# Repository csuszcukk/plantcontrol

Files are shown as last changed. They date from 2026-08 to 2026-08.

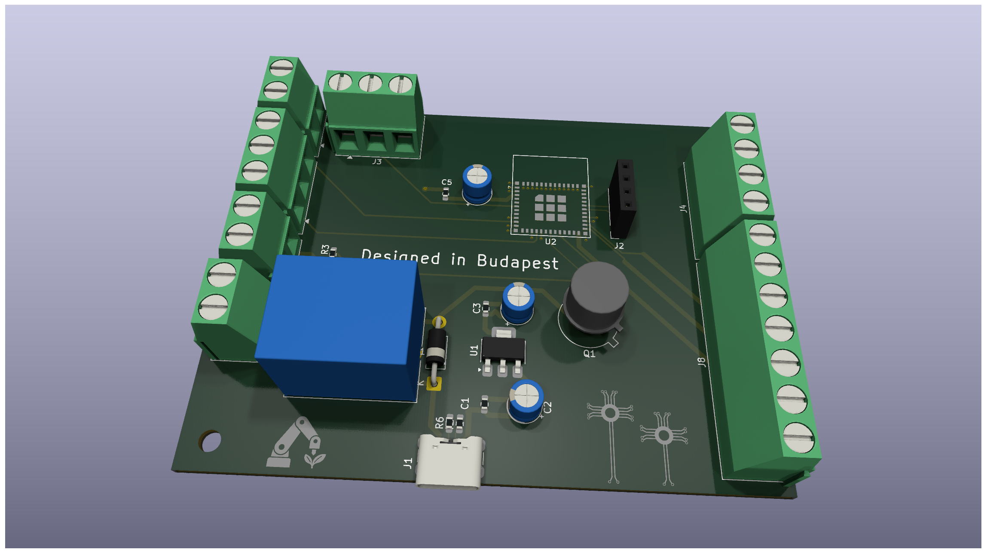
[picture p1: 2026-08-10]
pcb/mainboard/res/pcb.png

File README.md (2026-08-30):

# PlantControl
make a smart pot for plants



## Features

* Automatic watering and light control
* Humidity and temperature monitoring
* Soil temperature and moisture monitoring
* Low water level alert
* Custom water container design
* Compatible with all plants and pots

## How to Build It

1. **PCB Fabrication:** Order the PCBs from any manufacturer (ordering a stencil is recommended).
2. **Heat Dissipation (Optional):** If you plan to use LEDs, mount them on an aluminum sheet using thermal conductive tape for proper heat dissipation.
3. **Components:** Order the necessary components listed in the Bill of Materials (BOM) — feel free to modify or skip non-essential parts.
4. **3D Printing:** Print the structural parts (PLA is recommended for the main board enclosure, and PETG for the water container).
5. **Assembly:** Solder all components onto the PCB.
6. **Preparation:** Connect the boot configuration pins and plug in the power source.
7. **Flashing Interface:** Connect your USB-to-UART bridge (make sure RX and TX lines are swapped).
8. **Firmware Installation (MicroPython):** Flash the ESP32 with the MicroPython firmware (see the official [MicroPython ESP32 Documentation](https://docs.micropython.org/en/latest/esp32/tutorial/intro.html)).
9. **Uploading Code:** Flash `main.py` onto the board (follow this [MicroPython Flashing Guide](https://georgefreedom.com/ignition-sequence-how-to-flash-micropython-onto-your-esp32/)).
10. **Cleanup:** Remove the boot mode jumpers and the UART adapter, then disconnect power.
11. **Wiring:** Connect all peripherals and modules to their respective header pins (labels are silkscreened on the PCB for guidance).
12. **Final Mounting:** Secure the sensors and the main board inside the enclosure (double-sided mounting tape works great).
13. **Power On:** Reconnect power to the board.
14. **Done!** Your plant controller is ready to go.

> **Pro Tip:** On first boot (or if it cannot connect to a saved network), the device will host a Wi-Fi Access Point. Connect to it to enter your local Wi-Fi SSID and password via the captive portal. Don't forget to enter your ThingSpeak API key in the configuration file to enable telemetry logging!

## How It Works

PlantControl is an automated, ESP32-C6-powered plant monitoring and maintenance system running on custom MicroPython firmware. It continuously monitors environmental conditions and manages irrigation and lighting using asynchronous event loops.

### Core Architecture

* **Sensor Data Acquisition:** The system periodically samples soil moisture, ambient light, and air temperature/humidity levels. 
* **Automated Logic & Safety:** If soil moisture drops below the predefined threshold, the MCU triggers a relay/MOSFET to activate the water pump. It includes safety timers to prevent over-watering or running the pump dry.
* **Local UI & Status:** A circular GC9A01 SPI display provides real-time readout of plant metrics and device status directly on the enclosure.
* **Power & Load Management:** High-side MOSFET switching ensures power is delivered efficiently to peripherals (pumps, LEDs) only when needed, minimizing idle power consumption.
* **Connectivity & Telemetry:** Integrated Wi-Fi connects to local infrastructure to stream telemetry to ThingSpeak. If network connection fails, it automatically spins up a Wi-Fi Access Point with a captive portal for re-configuration.

## Component Sourcing & Logistics

To optimize the project budget and lead times, a hybrid sourcing strategy is used:

- **LCSC:** Used for standard SMD components, passives, ICs, and microcontrollers to take advantage of low bulk pricing.
- **HESTORE (EU Local Distributor):** Used for specific sensors, modules, and components unavailable on LCSC or needed quickly.

All BOM prices from HESTORE have been converted from HUF to USD using current market exchange rates.

## License

This project is licensed under the MIT License - see the [LICENSE](LICENSE) file for details.

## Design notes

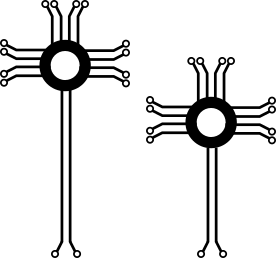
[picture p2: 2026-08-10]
pcb/mainboard/res/path1317-7.png

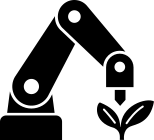
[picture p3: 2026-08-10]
pcb/mainboard/res/g1170.png

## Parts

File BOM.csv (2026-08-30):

Reference | Qty | Value | DNP | Exclude from BOM | Exclude from Board | Exclude from Simulation | Exclude from Position Files | Footprint | Datasheet | jlc part # | amazon link
J10 | 1 | Screw_Terminal_01x04 |  |  |  |  | ${EXCLUDE_FROM_POS_FILES} | TerminalBlock_Phoenix:TerminalBlock_Phoenix_MKDS-1,5-4_1x04_P5.00mm_Horizontal |  | C90087
R1 | 1 | 5,1k |  |  |  |  | ${EXCLUDE_FROM_POS_FILES} | Resistor_SMD:R_0603_1608Metric_Pad0.98x0.95mm_HandSolder |  | C177348
R4 | 1 | VT93xx |  |  |  |  | ${EXCLUDE_FROM_POS_FILES} | OptoDevice:R_LDR_4.9x4.2mm_P2.54mm_Vertical | http://www.produktinfo.conrad.com/datenblaetter/125000-149999/140375-da-01-en-FOTOWIDERSTAND__VT_93_N2__THT_.pdf | C10077
R5 | 1 | 10k |  |  |  |  | ${EXCLUDE_FROM_POS_FILES} | Resistor_SMD:R_0603_1608Metric_Pad0.98x0.95mm_HandSolder |  | C2906982
U3 | 1 | AM2302 |  |  |  |  | ${EXCLUDE_FROM_POS_FILES} | Sensor:ASAIR_AM2302_P2.54mm_Lead2.75mm_TabDown | http://akizukidenshi.com/download/ds/aosong/AM2302.pdf | C83988
USB1 | 1 | TYPE-C 6P |  |  |  |  |  | lcsc_import:TYPE-C-SMD_TYPE-C-6P-073 | https://lcsc.com/product-detail/USB-Connectors_SHOU-HAN-TYPE-C-6P-073_C668623.html | C668623
U2 | 1 | AMS1117-3.3 |  |  |  |  |  | Package_TO_SOT_SMD:SOT-223-3_TabPin2 | http://www.advanced-monolithic.com/pdf/ds1117.pdf | C6186
U1 | 1 | ESP32-C6-MINI-1 |  |  |  |  |  | Library:ESP32-C6-MINI-1psa | https://www.espressif.com/sites/default/files/documentation/esp32-c6-mini-1_mini-1u_datasheet_en.pdf | C5736265
R8,R9 | 2 | 5,1k |  |  |  |  |  | Resistor_SMD:R_0603_1608Metric_Pad0.98x0.95mm_HandSolder |  | C177348
R3 | 1 | 1k |  |  |  |  |  | Resistor_SMD:R_0603_1608Metric_Pad0.98x0.95mm_HandSolder |  | C2907002
R2,R4,R6,R7 | 4 | 10k |  |  |  |  |  | Resistor_SMD:R_0603_1608Metric_Pad0.98x0.95mm_HandSolder |  | C2906982
R1 | 1 | 470 |  |  |  |  |  | Resistor_SMD:R_0603_1608Metric_Pad0.98x0.95mm_HandSolder |  | C23179
Q2 | 1 | 2N2222A |  |  |  |  |  | Package_TO_SOT_THT:TO-39-3 | https://www.onsemi.com/pub/Collateral/2N3903-D.PDF | C118536
Q1 | 1 | AO3400A |  |  |  |  |  | Package_TO_SOT_SMD:SOT-23 | http://www.aosmd.com/pdfs/datasheet/AO3400A.pdf | C20917
K1 | 1 | SANYOU_SRD_Form_A |  |  |  |  |  | Relay_THT:Relay_SPDT_SANYOU_SRD_Series_Form_C | http://www.sanyourelay.ca/public/products/pdf/SRD.pdf | C35449
J11 | 1 | Conn_01x02_Pin |  |  |  |  |  | Connector_PinHeader_2.54mm:PinHeader_1x02_P2.54mm_Vertical |  | C37208
J8 | 1 | Conn_01x04_Pin |  |  |  |  |  | Connector_PinSocket_2.54mm:PinSocket_1x04_P2.54mm_Vertical |  | C37208
J6 | 1 | Screw_Terminal_01x07 |  |  |  |  |  | TerminalBlock_Phoenix:TerminalBlock_Phoenix_MKDS-1,5-7_1x07_P5.00mm_Horizontal |  | C395855
J4,J5 | 2 | Screw_Terminal_01x03 |  |  |  |  |  | TerminalBlock_Phoenix:TerminalBlock_Phoenix_MKDS-1,5-3_1x03_P5.00mm_Horizontal |  | C8270
J3,J7,J9 | 3 | Screw_Terminal_01x02 |  |  |  |  |  | TerminalBlock_Phoenix:TerminalBlock_Phoenix_MKDS-1,5-2_1x02_P5.00mm_Horizontal |  | C3703
J2 | 1 | Screw_Terminal_01x04 |  |  |  |  |  | TerminalBlock_Phoenix:TerminalBlock_Phoenix_MKDS-1,5-4_1x04_P5.00mm_Horizontal |  | C90087
D1 | 1 | 1N4001 |  |  |  |  |  | Diode_THT:D_DO-41_SOD81_P10.16mm_Horizontal | http://www.vishay.com/docs/88503/1n4001.pdf | C2456
C2,C4,C6 | 3 | 100nF |  |  |  |  |  | Resistor_SMD:R_0603_1608Metric_Pad0.98x0.95mm_HandSolder |  | C1591
C1,C3,C5 | 3 | 10uF |  |  |  |  |  | Capacitor_THT:CP_Radial_D5.0mm_P2.00mm |  | C216288
~ | 1 |  |  |  |  |  |  | small circle spi sreen | ~ | ~ | https://www.amazon.com/Screen-Display-240x240-Interface-Arduino/dp/B0GR44PSBL/132-4224079-3597343
~ | 1 |  |  |  |  |  |  | water sensor | ~ | ~ | https://www.amazon.com/Ximimark-Sensor-Horizontal-Switch-Arduino/dp/B0B7WPBPBC
~ | 1 |  |  |  |  |  |  | power suply for the led | ~ | ~ | https://www.amazon.com/dp/B0781JC2WK?_encoding=UTF8&psc=1
~ | 1 |  |  |  |  |  |  | usb module | ~ | ~ | https://www.amazon.com/DSD-TECH-SH-U09C2-Debugging-Programming/dp/B07TXVRQ7V
~ | 1 |  |  |  |  |  |  | soil moistor sensor | ~ | ~ | https://www.amazon.com/VKLSVAN-Capacitive-Corrosion-Resistant-Detection/dp/B0DQSCD5CV
~ | 1 | 5V |  |  |  |  |  | pump | ~ | ~ | https://www.amazon.com/dp/B09GW5X4P2?_encoding=UTF8&psc=1
~ | 2m |  |  |  |  |  |  | pipes for the pump | ~ | ~ | https://www.amazon.com/Silicone-Flexible-Rubber-Tubing-Transparent/dp/B08HJJ13FG?
~ | 1 |  |  |  |  |  |  | Red Led | ~ | ~ | https://www.amazon.com/Cleiscry-Power-3W-Emitter-Components/dp/B0BKSL2HCC
~ | 1 |  |  |  |  |  |  | Blue Led | ~ | ~ | https://www.amazon.com/Cleiscry-Power-3W-Emitter-Components/dp/B0BKSMD3P9/ref=sr_1_4
 | 1 |  |  |  |  |  |  | power suply for the pump | ~ | ~ | same as the led but an another modul
 | 1 |  |  |  |  |  |  | termal tape |  | ~ | https://www.amazon.com/Thermal-Adhesive-Performance-Heatsink-Computer/dp/B085CLXM7J/ref=sr_1_3
 | 1 |  |  |  |  |  |  | plant pot |  | ~ | https://www.amazon.com/Dvine-Dev-Decorative-Gardening-Succulents/dp/B0D1G1N9BP/ref=sr_1_13

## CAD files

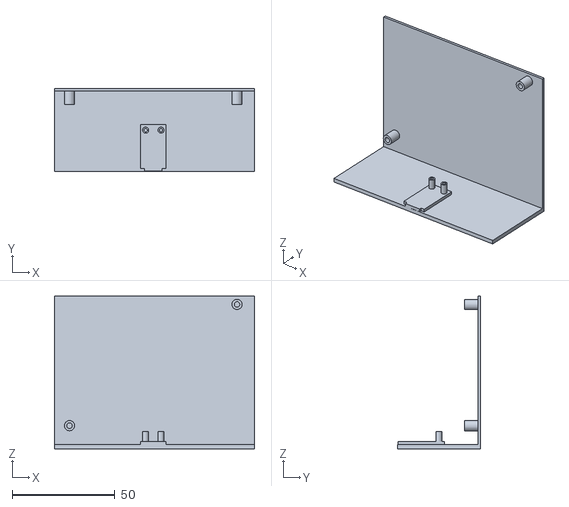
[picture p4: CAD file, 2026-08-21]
cad models/main board carrier.stl
97.3 x 40.2 x 74.2

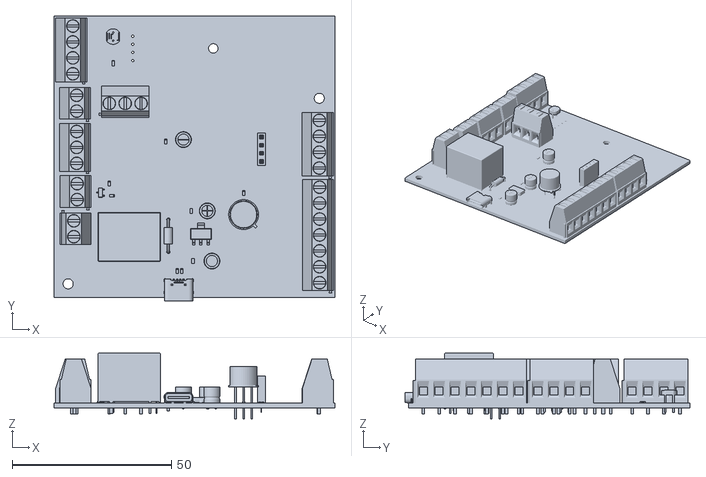
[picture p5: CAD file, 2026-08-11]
cad models/stl/main board.stl
88.3 x 89.4 x 20.6

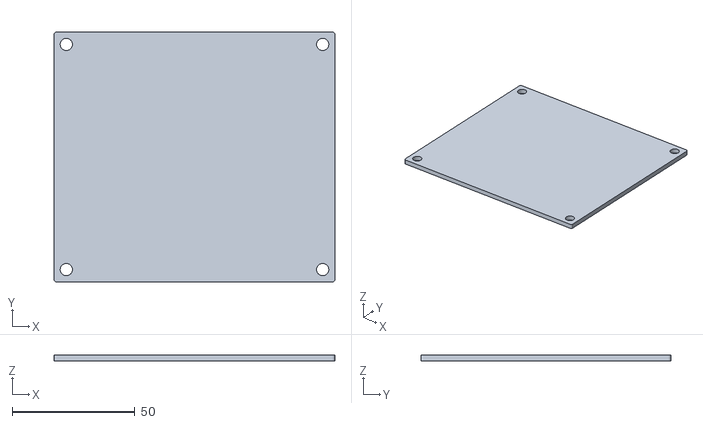
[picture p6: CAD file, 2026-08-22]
cad models/stl/led board.stl
114.3 x 101.6 x 2.50

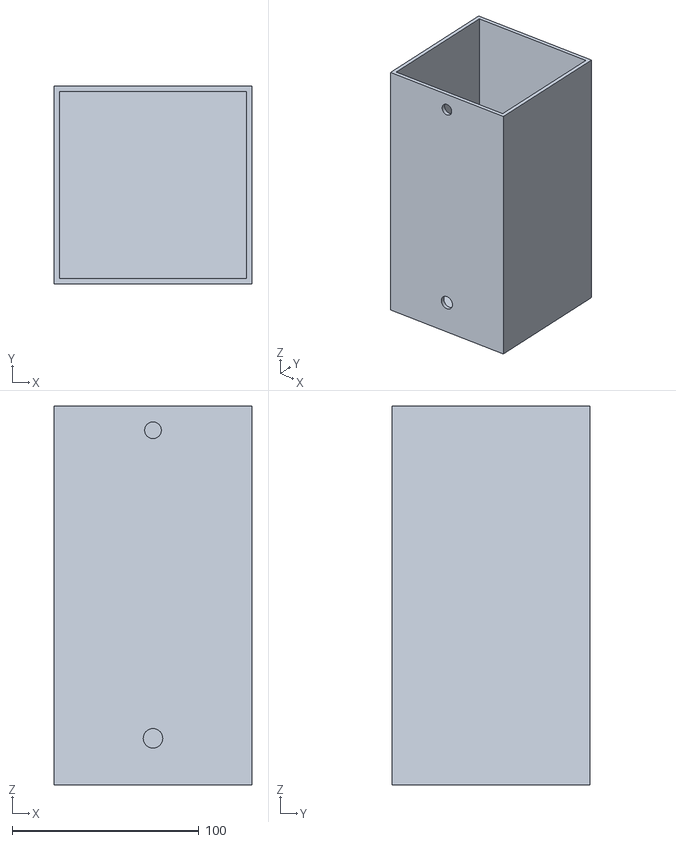
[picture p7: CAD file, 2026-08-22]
cad models/stl/watercontainer.stl
106.0 x 106.0 x 203.0

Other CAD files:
pcb/mainboard/pcb.step
cad models/stl/main board carrier.stl

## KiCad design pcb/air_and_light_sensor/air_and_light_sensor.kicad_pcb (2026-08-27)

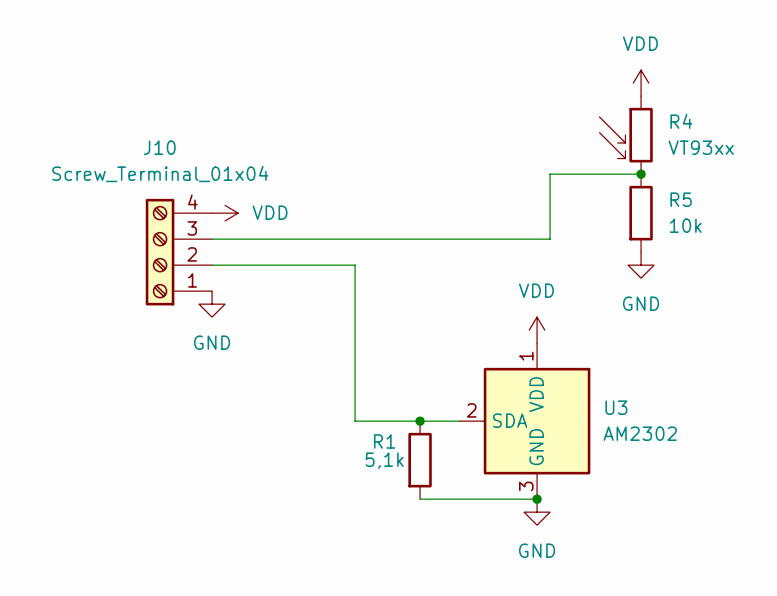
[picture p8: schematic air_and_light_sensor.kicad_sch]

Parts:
J10: Screw_Terminal_01x04; TerminalBlock_Phoenix_MKDS-1,5-4_1x04_P5.00mm_Horizontal; jlc part # C90087
R1: 5,1k; R_0603_1608Metric_Pad0.98x0.95mm_HandSolder; jlc part # C177348
R4: VT93xx; R_LDR_4.9x4.2mm_P2.54mm_Vertical; jlc part # C10077
R5: 10k; R_0603_1608Metric_Pad0.98x0.95mm_HandSolder; jlc part # C2906982
U3: AM2302; ASAIR_AM2302_P2.54mm_Lead2.75mm_TabDown; jlc part # C83988

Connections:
GND: J10.1, R1.2, R5.2, U3.3 (GND), U3.4 (GND)
unnamed: J10.2, R1.1, U3.2 (SDA)
unnamed: J10.3, R4.2, R5.1
VDD: J10.4, R4.1, U3.1 (VDD)

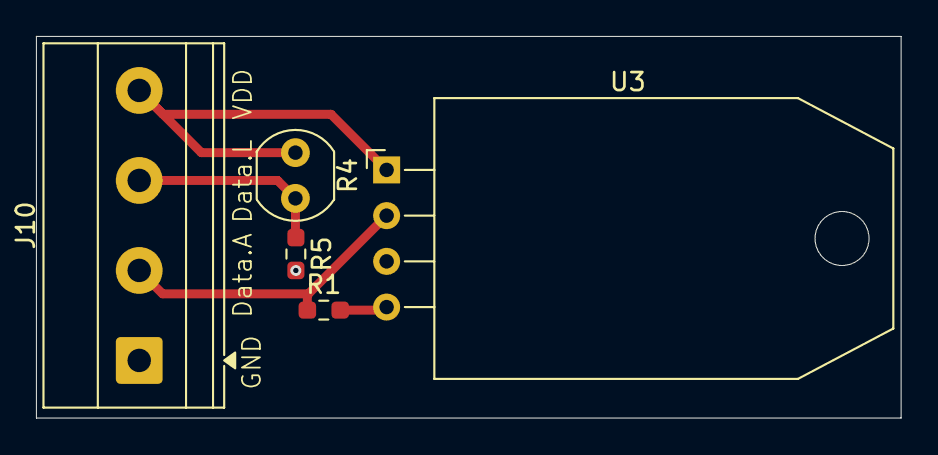
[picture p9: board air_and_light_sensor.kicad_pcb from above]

Board: 2 copper layers, 48.0 x 21.2 mm, 5 parts (0 on the bottom side), 4 nets.

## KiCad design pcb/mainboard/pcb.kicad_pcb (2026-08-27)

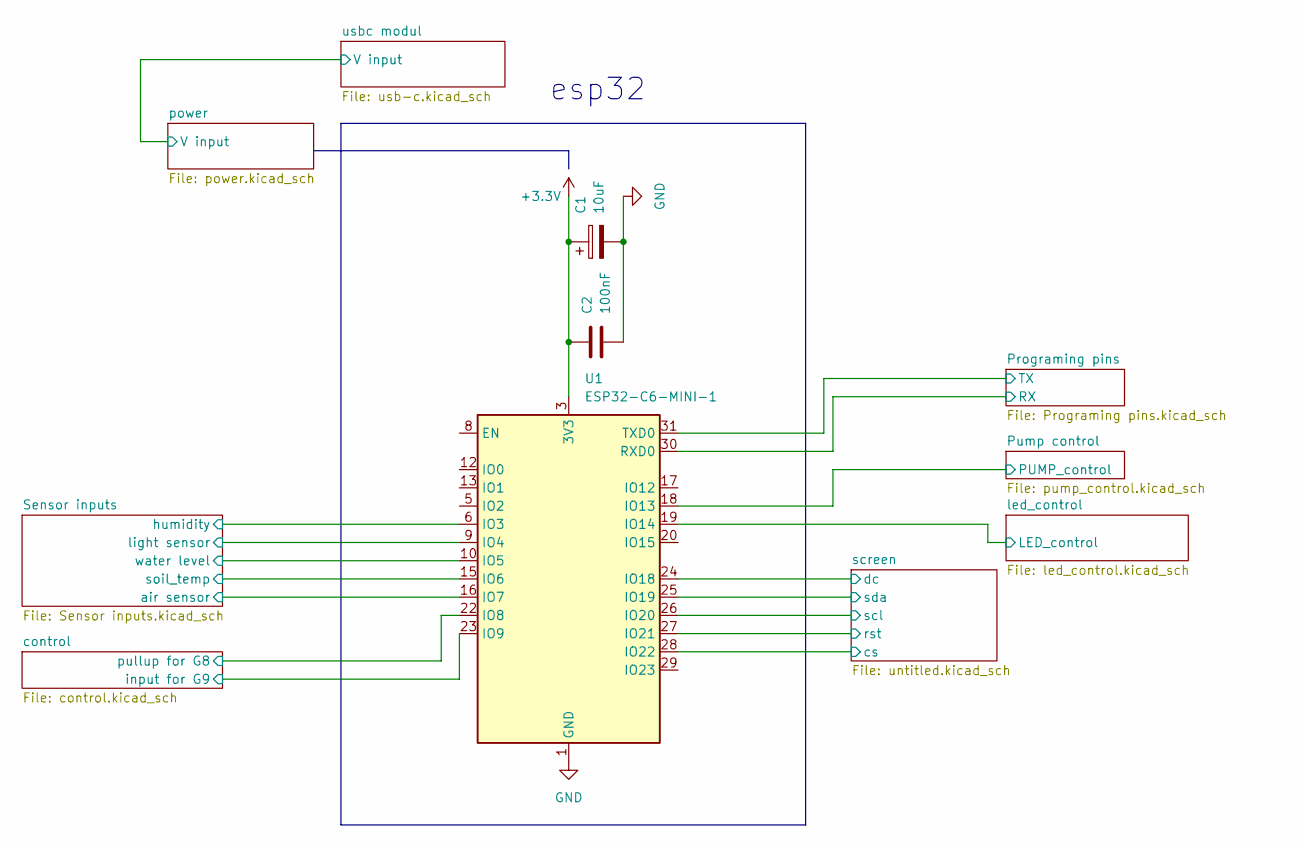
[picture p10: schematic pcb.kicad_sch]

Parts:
C1: 10uF; CP_Radial_D5.0mm_P2.00mm; jlc part # C216288
C2: 100nF; R_0603_1608Metric_Pad0.98x0.95mm_HandSolder; jlc part # C1591
U1: ESP32-C6-MINI-1; ESP32-C6-MINI-1psa; jlc part # C5736265

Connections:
+3.3V: C1.1, C2.1, U1.3 (3V3); also elsewhere on the board
/Programing pins/RX: U1.30 (RXD0); also elsewhere on the board
/Programing pins/TX: U1.31 (TXD0); also elsewhere on the board
/Pump control/PUMP_control: U1.18 (IO13); also elsewhere on the board
/Sensor inputs/air sensor: U1.16 (IO7); also elsewhere on the board
/Sensor inputs/humidity: U1.6 (IO3); also elsewhere on the board
/Sensor inputs/light sensor: U1.9 (IO4); also elsewhere on the board
/Sensor inputs/soil_temp: U1.15 (IO6); also elsewhere on the board
/Sensor inputs/water level: U1.10 (IO5); also elsewhere on the board
/control/input for G9: U1.23 (IO9); also elsewhere on the board
/control/pullup for G8: U1.22 (IO8); also elsewhere on the board
/led_control/LED_control: U1.19 (IO14); also elsewhere on the board
/screen/cs: U1.28 (IO22); also elsewhere on the board
/screen/dc: U1.24 (IO18); also elsewhere on the board
/screen/rst: U1.27 (IO21); also elsewhere on the board
/screen/scl: U1.26 (IO20); also elsewhere on the board
/screen/sda: U1.25 (IO19); also elsewhere on the board
GND: C1.2, C2.2, U1.1 (GND), U1.2 (GND), U1.11 (GND), U1.14 (GND), U1.36 (GND), U1.37 (GND), U1.38 (GND), U1.39 (GND), U1.40 (GND), U1.41 (GND), U1.42 (GND), U1.43 (GND), U1.44 (GND), U1.45 (GND), U1.46 (GND), U1.47 (GND), U1.48 (GND), U1.49 (GND), U1.50 (GND), U1.51 (GND), U1.52 (GND), U1.53 (GND); also elsewhere on the board

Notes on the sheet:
esp32

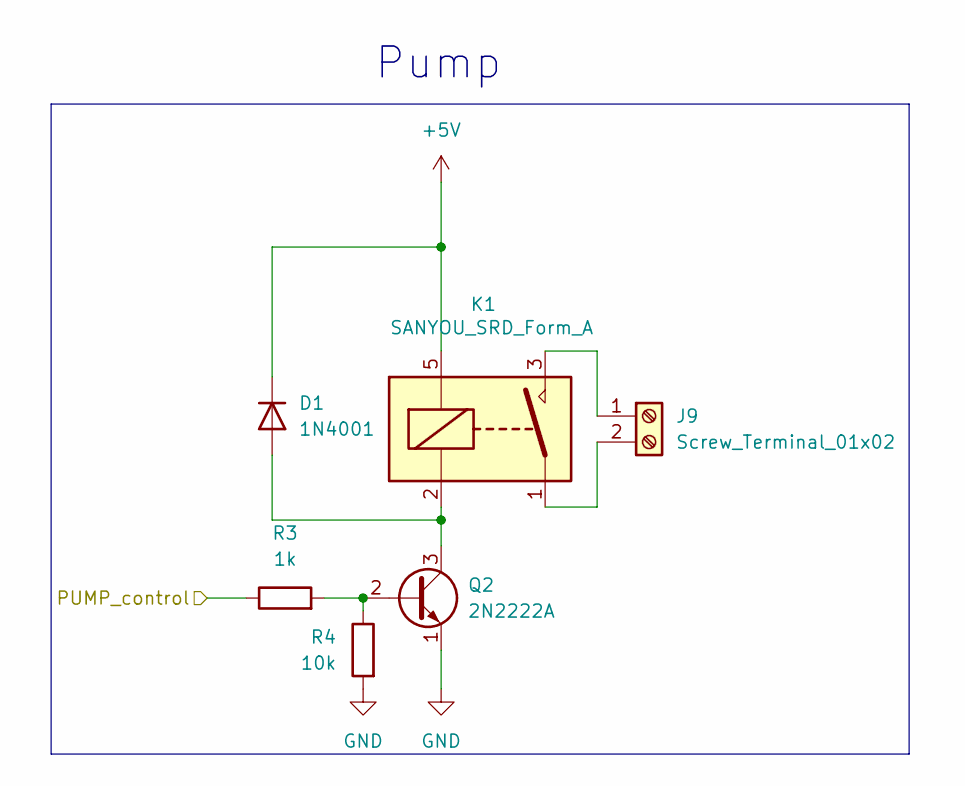
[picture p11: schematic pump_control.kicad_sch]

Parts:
D1: 1N4001; D_DO-41_SOD81_P10.16mm_Horizontal; jlc part # C2456
J9: Screw_Terminal_01x02; TerminalBlock_Phoenix_MKDS-1,5-2_1x02_P5.00mm_Horizontal; jlc part # C3703
K1: SANYOU_SRD_Form_A; Relay_SPDT_SANYOU_SRD_Series_Form_C; jlc part # C35449
Q2: 2N2222A; TO-39-3; jlc part # C118536
R3: 1k; R_0603_1608Metric_Pad0.98x0.95mm_HandSolder; jlc part # C2907002
R4: 10k; R_0603_1608Metric_Pad0.98x0.95mm_HandSolder

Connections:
+5V: D1.1 (K), K1.5; also elsewhere on the board
/Pump control/PUMP_control: R3.1; also elsewhere on the board
GND: Q2.1 (E), R4.2; also elsewhere on the board
unnamed: D1.2 (A), K1.2, Q2.3 (C)
unnamed: J9.1, K1.3
unnamed: J9.2, K1.1
unnamed: Q2.2 (B), R3.2, R4.1

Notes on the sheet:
Pump

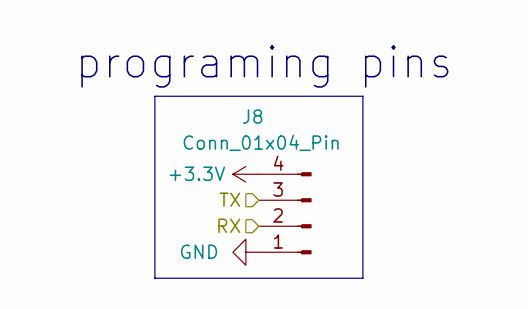
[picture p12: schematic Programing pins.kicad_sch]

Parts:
J8: Conn_01x04_Pin; PinSocket_1x04_P2.54mm_Vertical; jlc part # C37208

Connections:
+3.3V: J8.4; also elsewhere on the board
/Programing pins/RX: J8.2; also elsewhere on the board
/Programing pins/TX: J8.3; also elsewhere on the board
GND: J8.1; also elsewhere on the board

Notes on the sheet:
programing pins

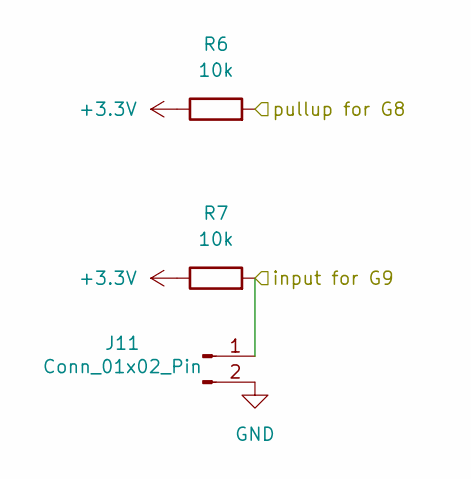
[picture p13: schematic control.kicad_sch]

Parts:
J11: Conn_01x02_Pin; PinHeader_1x02_P2.54mm_Vertical; jlc part # C37208
R6, R7: 10k; R_0603_1608Metric_Pad0.98x0.95mm_HandSolder; jlc part # C2906982

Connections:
+3.3V: R6.1, R7.1; also elsewhere on the board
/control/input for G9: J11.1, R7.2; also elsewhere on the board
/control/pullup for G8: R6.2; also elsewhere on the board
GND: J11.2; also elsewhere on the board

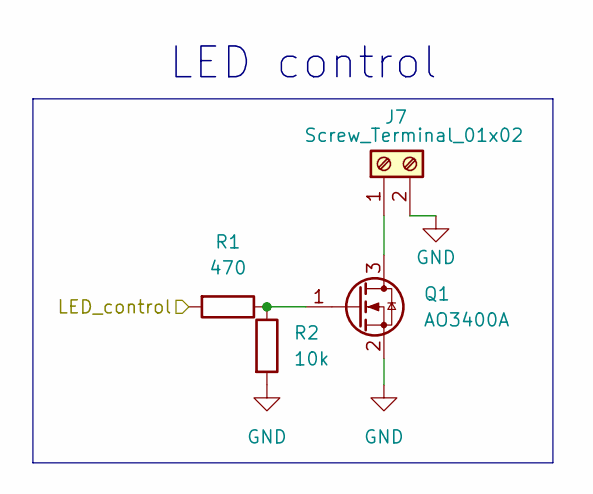
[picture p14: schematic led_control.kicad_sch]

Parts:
J7: Screw_Terminal_01x02; TerminalBlock_Phoenix_MKDS-1,5-2_1x02_P5.00mm_Horizontal; jlc part # C3703
Q1: AO3400A; SOT-23; jlc part # C20917
R1: 470; R_0603_1608Metric_Pad0.98x0.95mm_HandSolder; jlc part # C23179
R2: 10k; R_0603_1608Metric_Pad0.98x0.95mm_HandSolder; jlc part # C2906982

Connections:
/led_control/LED_control: R1.2; also elsewhere on the board
GND: J7.2, Q1.2 (S), R2.2; also elsewhere on the board
unnamed: J7.1, Q1.3 (D)
unnamed: Q1.1 (G), R1.1, R2.1

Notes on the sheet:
LED control

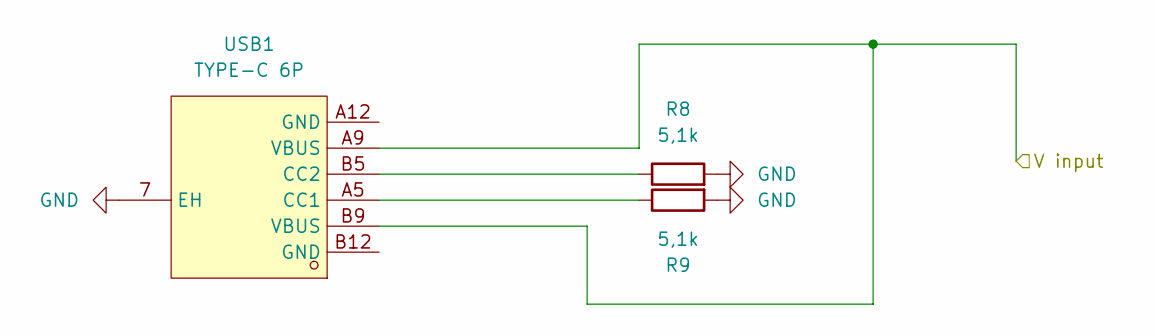
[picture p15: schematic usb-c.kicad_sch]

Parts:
R8, R9: 5,1k; R_0603_1608Metric_Pad0.98x0.95mm_HandSolder; jlc part # C177348
USB1: TYPE-C 6P; TYPE-C-SMD_TYPE-C-6P-073; MPN TYPE-C 6P(073); jlc part # C668623

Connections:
+5V: USB1.A9 (VBUS), USB1.B9 (VBUS); also elsewhere on the board
GND: R8.2, R9.2, USB1.7 (EH); also elsewhere on the board
unnamed: R9.1, USB1.A5 (CC1)
unnamed: R8.1, USB1.B5 (CC2)

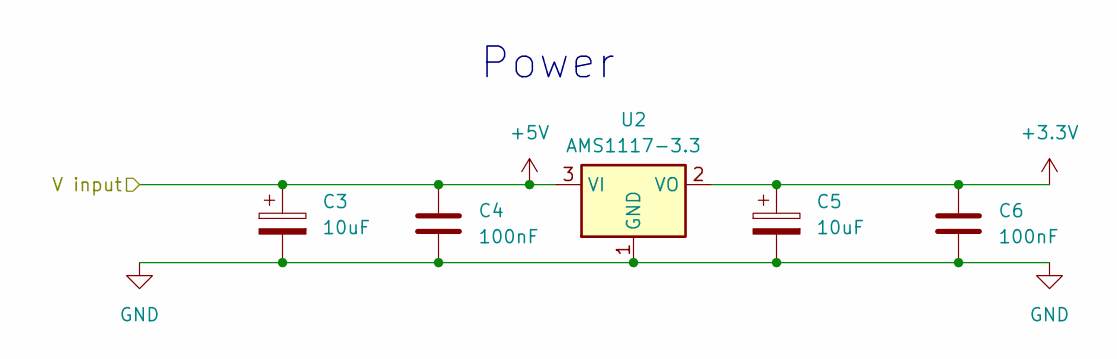
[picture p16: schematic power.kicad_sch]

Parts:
C3, C5: 10uF; CP_Radial_D5.0mm_P2.00mm; jlc part # C216288
C4, C6: 100nF; R_0603_1608Metric_Pad0.98x0.95mm_HandSolder; jlc part # C1591
U2: AMS1117-3.3; SOT-223-3_TabPin2; jlc part # C6186

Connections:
+3.3V: C5.1, C6.1, U2.2 (VO); also elsewhere on the board
+5V: C3.1, C4.1, U2.3 (VI); also elsewhere on the board
GND: C3.2, C4.2, C5.2, C6.2, U2.1 (GND); also elsewhere on the board

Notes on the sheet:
Power

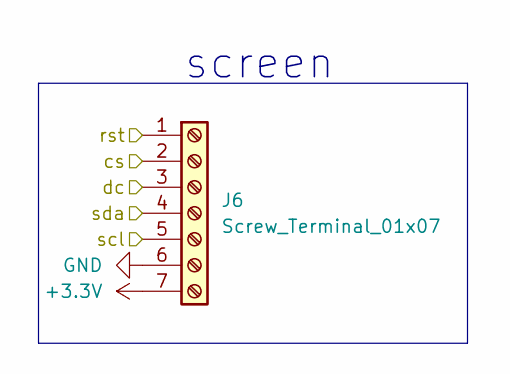
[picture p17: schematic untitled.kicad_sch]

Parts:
J6: Screw_Terminal_01x07; TerminalBlock_Phoenix_MKDS-1,5-7_1x07_P5.00mm_Horizontal; jlc part # C395855

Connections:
+3.3V: J6.7; also elsewhere on the board
/screen/cs: J6.2; also elsewhere on the board
/screen/dc: J6.3; also elsewhere on the board
/screen/rst: J6.1; also elsewhere on the board
/screen/scl: J6.5; also elsewhere on the board
/screen/sda: J6.4; also elsewhere on the board
GND: J6.6; also elsewhere on the board

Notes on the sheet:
screen

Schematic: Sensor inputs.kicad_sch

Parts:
J2: Screw_Terminal_01x04; TerminalBlock_Phoenix_MKDS-1,5-4_1x04_P5.00mm_Horizontal; jlc part # C90087
J3: Screw_Terminal_01x02; TerminalBlock_Phoenix_MKDS-1,5-2_1x02_P5.00mm_Horizontal; jlc part # C3703
J4, J5: Screw_Terminal_01x03; TerminalBlock_Phoenix_MKDS-1,5-3_1x03_P5.00mm_Horizontal; jlc part # C8270

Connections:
+3.3V: J2.4, J4.3, J5.3; also elsewhere on the board
/Sensor inputs/air sensor: J2.2; also elsewhere on the board
/Sensor inputs/humidity: J5.2; also elsewhere on the board
/Sensor inputs/light sensor: J2.3; also elsewhere on the board
/Sensor inputs/soil_temp: J4.2; also elsewhere on the board
/Sensor inputs/water level: J3.1; also elsewhere on the board
GND: J2.1, J3.2, J4.1, J5.1; also elsewhere on the board

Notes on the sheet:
water level sensor
soil tempature input
light and air sensor input
soil humuidity input

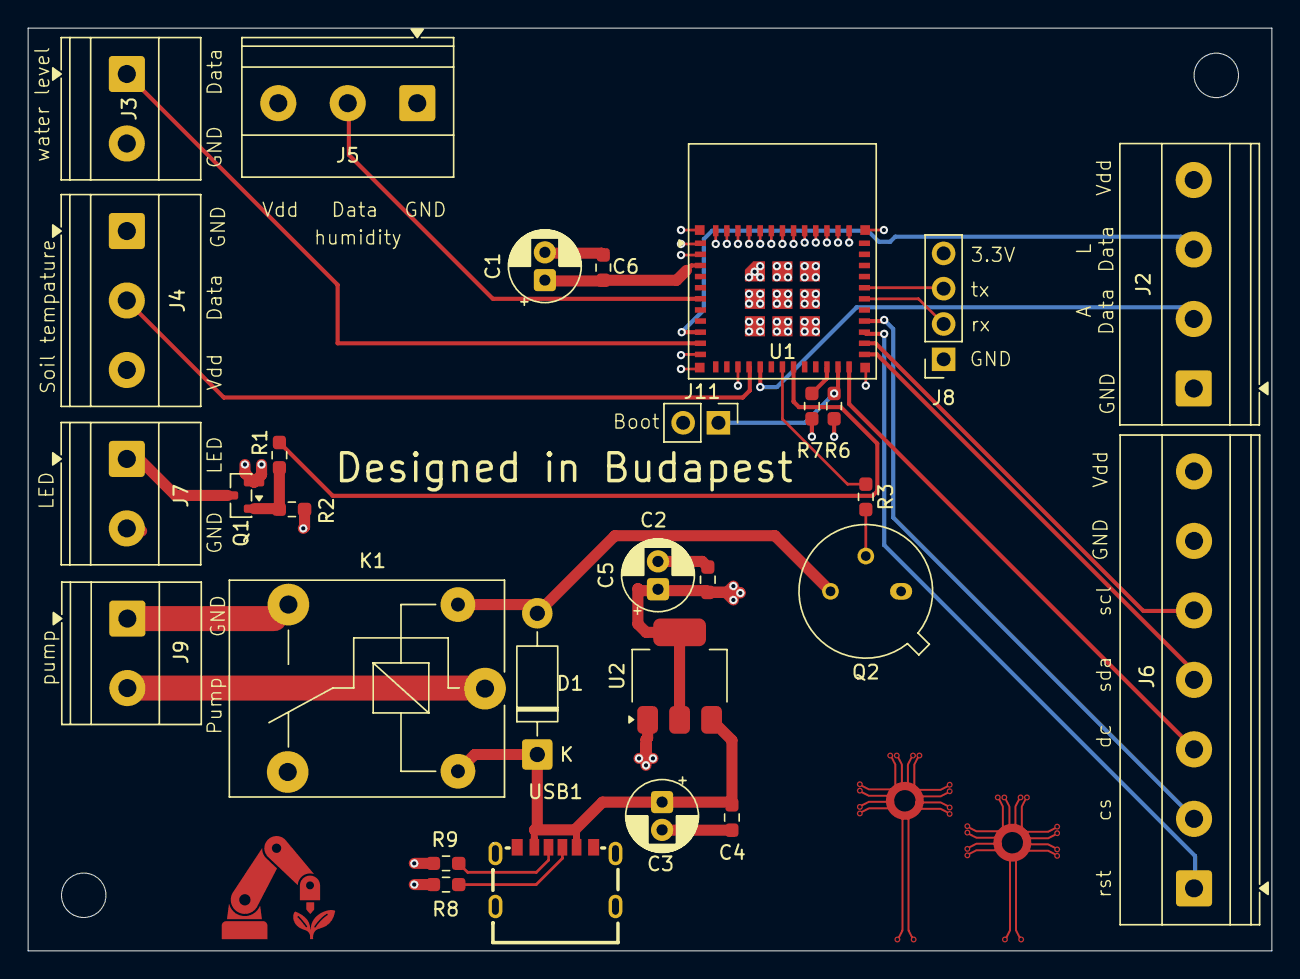
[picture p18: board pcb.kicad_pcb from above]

Board: 4 copper layers, 89.5 x 66.4 mm, 29 parts (0 on the bottom side), 27 nets.

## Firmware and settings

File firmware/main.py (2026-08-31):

from machine import Pin, SPI, ADC, PWM
import uasyncio as asyncio
import wifimanager
import dht
import urequests
import json
import gc9a01
import gc9a01
import vga1_8x16 as font 

wlan = wifimanager.get_connection()

if wlan and wlan.isconnected():
    print("Sikeres netcsatlakozás! IP:", wlan.ifconfig()[0])

url = "https://api.thingspeak.com/update"
headers = {'Content-Type': 'application/json'}

# ThingSpeak kötelező api_key mezővel
payload = {
    "api_key": "Type the API key here",
    "field1": 0.0,
    "field2": 0.0,
    "field3": 0.0,
    "field4": 0.0
}

# --- GC9A01 Inicializálás ---
# SPI busz inicializálása a rajz szerinti lábakkal (sck=IO20, mosi=IO19)
spi = SPI(1, baudrate=60000000, sck=Pin(20), mosi=Pin(19))

# Kijelző inicializálása
display = gc9a01.GC9A01(
    spi,
    dc=Pin(18, Pin.OUT),
    cs=Pin(22, Pin.OUT),
    reset=Pin(21, Pin.OUT),
    rotation=0
)

def draw_bar(display, x, y, w, h, percentage, color):
    """ Progress bar kirajzolása """
    percentage = max(0, min(100, percentage))
    
    # 1. Keret
    display.hline(x, y, w, color)
    display.hline(x, y + h - 1, w, color)
    display.vline(x, y, h, color)
    display.vline(x + w - 1, y, h, color)
    
    # 2. Háttér ürítése feketére
    display.fill_rect(x + 1, y + 1, w - 2, h - 2, gc9a01.BLACK)
    
    # 3. Érték kitöltése
    fill_w = int((w - 2) * (percentage / 100))
    if fill_w > 0:
        display.fill_rect(x + 1, y + 1, fill_w, h - 2, color)

async def update_display():
    while True:
        try:
            temp = payload.get('field1', 0.0)
            hum = payload.get('field2', 0.0)
            soil_m = payload.get('field3', 0)

            # Százalékos értékek kiszámítása
            temp_pct = int((temp / 50.0) * 100)
            hum_pct = int(hum)
            soil_pct = int((soil_m / 65535) * 100)

            # Kijelző törlése
            display.fill(gc9a01.BLACK)

            # Fejléc
            display.text(font, "PLANT MONITOR", 60, 25, gc9a01.WHITE, gc9a01.BLACK)

            # --- Hőmérséklet ---
            display.text(font, f"Temp: {temp:.1f}C", 40, 60, gc9a01.GREEN, gc9a01.BLACK)
            draw_bar(display, 40, 80, 160, 12, temp_pct, gc9a01.GREEN)

            # --- Páratartalom ---
            display.text(font, f"Humi: {hum:.1f}%", 40, 105, gc9a01.BLUE, gc9a01.BLACK)
            draw_bar(display, 40, 125, 160, 12, hum_pct, gc9a01.BLUE)

            # --- Talajnedvesség ---
            display.text(font, f"Soil: {soil_m}", 40, 150, gc9a01.YELLOW, gc9a01.BLACK)
            draw_bar(display, 40, 170, 160, 12, soil_pct, gc9a01.YELLOW)

        except Exception as e:
            print("Error updating display:", e)

        await asyncio.sleep(2)
async def read_dht_sensor():
    dht_sensor = dht.DHT22(Pin(7)) # Ha a rajz szerint van: Pin(3)
    while True:
        try:
            dht_sensor.measure()
            temperature = dht_sensor.temperature()
            humidity = dht_sensor.humidity()
            print("Temp.: {:.2f} °C, Humidity: {:.2f} %".format(temperature, humidity))
            payload['field1'] = temperature
            payload['field2'] = humidity
        except Exception as e:
            print("Error during reading DHT22 sensor:", e)
        await asyncio.sleep(2)

async def read_Soil_moisture_sensor():
    soil_moisture_sensor = ADC(Pin(3))
    soil_moisture_sensor.atten(ADC.ATTN_11DB) # 0-3.3V méréshatár!
    while True:
        try:
            soil_moisture_value = soil_moisture_sensor.read_u16()
            print("Soil Moisture Value:", soil_moisture_value)
            payload['field3'] = soil_moisture_value
        except Exception as e:
            print("Error during reading Soil Moisture sensor:", e)
        await asyncio.sleep(5)

async def read_Soil_temperature_sensor():
    soil_temp_sensor = ADC(Pin(6))
    soil_temp_sensor.atten(ADC.ATTN_11DB) # 0-3.3V méréshatár!
    while True:
        try:
            soil_temp_value = soil_temp_sensor.read_u16()
            print("Soil Temperature Value:", soil_temp_value)
            payload['field4'] = soil_temp_value
        except Exception as e:
            print("Error during reading Soil Temperature sensor:", e)
        await asyncio.sleep(5)

async def send_data():
    while True:
        try:
            # Csak akkor küldünk, ha van net
            if wlan and wlan.isconnected():
                response = urequests.post(url, data=json.dumps(payload), headers=headers)
                print("Data sent to ThingSpeak. Response:", response.text)
                response.close() # Nagyon fontos memóriaszivárgás ellen!
        except Exception as e:
            print("Error sending data to ThingSpeak:", e)
        
        # A ThingSpeak ingyenes limitje miatt MINIMUM 15-20 mp kell!
        await asyncio.sleep(20)

async def control_pump():
    pump = Pin(13, Pin.OUT, value=0) # Ha a rajz szerint van: Pin(8)
    while True:
        if 'field3' in payload and float(payload['field3']) < 20000:
            print("Pump ON")
            pump.value(1)
            await asyncio.sleep(5)
            pump.value(0)
            print("Pump OFF, waiting 15 mins...")
            await asyncio.sleep(900)  # 15 perc várakozás
        await asyncio.sleep(5)

async def led_control():
    Light_sensor = ADC(Pin(2))
    Light_sensor.atten(ADC.ATTN_11DB)
    LED = PWM(Pin(14), freq=1000) # Ha a rajz szerint van: Pin(15)
    
    while True:
        # A beolvasás bekerült a ciklusba!
        raw_val = Light_sensor.read()
        
        target_duty = 65535 - int((raw_val / 4095) * 65535)
        target_duty = max(0, min(65535, target_duty))

        LED.duty_u16(target_duty)
        await asyncio.sleep_ms(50)

async def main():
    asyncio.create_task(read_dht_sensor())
    asyncio.create_task(read_Soil_moisture_sensor())
    asyncio.create_task(read_Soil_temperature_sensor())
    asyncio.create_task(send_data())
    asyncio.create_task(control_pump())
    asyncio.create_task(led_control())
    
    while True:
        await asyncio.sleep(1)

asyncio.run(main())

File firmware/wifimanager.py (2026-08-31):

import network
import socket
import ure
import time

ap_ssid = "WifiManager"
ap_password = "tayfunulu"
ap_authmode = 3  # WPA2

NETWORK_PROFILES = 'wifi.dat'

wlan_ap = network.WLAN(network.AP_IF)
wlan_sta = network.WLAN(network.STA_IF)

server_socket = None


def get_connection():
    """return a working WLAN(STA_IF) instance or None"""

    # First check if there already is any connection:
    if wlan_sta.isconnected():
        return wlan_sta

    connected = False
    try:
        # ESP connecting to WiFi takes time, wait a bit and try again:
        time.sleep(3)
        if wlan_sta.isconnected():
            return wlan_sta

        # Read known network profiles from file
        profiles = read_profiles()

        # Search WiFis in range
        wlan_sta.active(True)
        networks = wlan_sta.scan()

        AUTHMODE = {0: "open", 1: "WEP", 2: "WPA-PSK", 3: "WPA2-PSK", 4: "WPA/WPA2-PSK"}
        for ssid, bssid, channel, rssi, authmode, hidden in sorted(networks, key=lambda x: x[3], reverse=True):
            ssid = ssid.decode('utf-8')
            encrypted = authmode > 0
            print("ssid: %s chan: %d rssi: %d authmode: %s" % (ssid, channel, rssi, AUTHMODE.get(authmode, '?')))
            if encrypted:
                if ssid in profiles:
                    password = profiles[ssid]
                    connected = do_connect(ssid, password)
                else:
                    print("skipping unknown encrypted network")
            else:  # open
                connected = do_connect(ssid, None)
            if connected:
                break

    except OSError as e:
        print("exception", str(e))

    # start web server for connection manager:
    if not connected:
        connected = start()

    return wlan_sta if connected else None


def read_profiles():
    with open(NETWORK_PROFILES) as f:
        lines = f.readlines()
    profiles = {}
    for line in lines:
        ssid, password = line.strip("\n").split(";")
        profiles[ssid] = password
    return profiles


def write_profiles(profiles):
    lines = []
    for ssid, password in profiles.items():
        lines.append("%s;%s\n" % (ssid, password))
    with open(NETWORK_PROFILES, "w") as f:
        f.write(''.join(lines))


def do_connect(ssid, password):
    wlan_sta.active(True)
    if wlan_sta.isconnected():
        return None
    print('Trying to connect to %s...' % ssid)
    wlan_sta.connect(ssid, password)
    for retry in range(200):
        connected = wlan_sta.isconnected()
        if connected:
            break
        time.sleep(0.1)
        print('.', end='')
    if connected:
        print('\nConnected. Network config: ', wlan_sta.ifconfig())
        
    else:
        print('\nFailed. Not Connected to: ' + ssid)
    return connected


def send_header(client, status_code=200, content_length=None ):
    client.sendall("HTTP/1.0 {} OK\r\n".format(status_code))
    client.sendall("Content-Type: text/html\r\n")
    if content_length is not None:
      client.sendall("Content-Length: {}\r\n".format(content_length))
    client.sendall("\r\n")


def send_response(client, payload, status_code=200):
    content_length = len(payload)
    send_header(client, status_code, content_length)
    if content_length > 0:
        client.sendall(payload)
    client.close()


def handle_root(client):
    wlan_sta.active(True)
    ssids = sorted(ssid.decode('utf-8') for ssid, *_ in wlan_sta.scan())
    send_header(client)
    client.sendall("""\
        <html>
            <h1 style="color: #5e9ca0; text-align: center;">
                <span style="color: #ff0000;">
                    Wi-Fi Client Setup
                </span>
            </h1>
            <form action="configure" method="post">
                <table style="margin-left: auto; margin-right: auto;">
                    <tbody>
    """)
    while len(ssids):
        ssid = ssids.pop(0)
        client.sendall("""\
                        <tr>
                            <td colspan="2">
                                <input type="radio" name="ssid" value="{0}" />{0}
                            </td>
                        </tr>
        """.format(ssid))
    client.sendall("""\
                        <tr>
                            <td>Password:</td>
                            <td><input name="password" type="password" /></td>
                        </tr>
                    </tbody>
                </table>
                <p style="text-align: center;">
                    <input type="submit" value="Submit" />
                </p>
            </form>
            <p>&nbsp;</p>
            <hr />
            <h5>
                <span style="color: #ff0000;">
                    Your ssid and password information will be saved into the
                    "%(filename)s" file in your ESP module for future usage.
                    Be careful about security!
                </span>
            </h5>
            <hr />
            <h2 style="color: #2e6c80;">
                Some useful infos:
            </h2>
            <ul>
                <li>
                    Original code from <a href="https://github.com/cpopp/MicroPythonSamples"
                        target="_blank" rel="noopener">cpopp/MicroPythonSamples</a>.
                </li>
                <li>
                    This code available at <a href="https://github.com/tayfunulu/WiFiManager"
                        target="_blank" rel="noopener">tayfunulu/WiFiManager</a>.
                </li>
            </ul>
        </html>
    """ % dict(filename=NETWORK_PROFILES))
    client.close()
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

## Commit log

2026-08-02 making a draft BOM
    [bom plant.ods]
2026-08-02 creating the project in kicad
    [bom plant.ods, pcb.kicad_pcb, pcb.kicad_sch]
2026-08-02 i forget the files before
    [pcb.kicad_sch]
2026-08-02 again i forget the file
    [bom plant.ods]
2026-08-02 fixing some issue
    [bom plant.ods, pcb.kicad_sch]
2026-08-02 adding screw terminals for the sensors
    [pcb.kicad_sch]
2026-08-02 the files... again
    [pcb.kicad_sch]
2026-08-02 adding the SPI screen
    [pcb.kicad_sch]
2026-08-03 cleaning the schematic
    [pcb.kicad_sch]
2026-08-05 Adding the MOSFET circuit
    [pcb.kicad_sch]
2026-08-06 makin the shematic hirearhic
    [Programing pins.kicad_sch, Sensor inputs.kicad_sch, bom plant.ods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]
2026-08-06 adding the lightresistor with the voltage devider circuit
    [light_sensor.kicad_sch, pcb.kicad_sch]
2026-08-06 cleaning the BOM
    [bom plant.ods]
2026-08-06 redesigning the circuit of the rellay and starting to adjust the footprints
    [Programing pins.kicad_sch, Sensor inputs.kicad_sch, led_control.kicad_sch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]
2026-08-06 finishing the bom and adding the jlc number of the parts
    [Programing pins.kicad_sch, Sensor inputs.kicad_sch, led_control.kicad_sch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]
2026-08-06 redesigning the power input
    [BOM.csv, BOM.ods, power.kicad_sch]
2026-08-06 adding the components
    [BOM.csv, pcb.kicad_pcb, power.kicad_sch]
2026-08-07 placing the components
    [pcb.kicad_pcb, pump_control.kicad_sch]
2026-08-07 aligning components and routing
    [pcb.kicad_pcb]
2026-08-07 finishing the pathing
    [pcb.kicad_pcb]
2026-08-09 realigning the pcb
    [pcb.kicad_pcb, pcb.kicad_sch]
2026-08-10 finishing the pcb
    [BOM.csv, pcb.kicad_pcb]
2026-08-10 adding text to the pcb
    [pcb.kicad_pcb]
2026-08-10 polishing the pcb
    [light_sensor.kicad_sch, pcb.kicad_pcb]
2026-08-10 Add PCB image to README
    Added an image of the PCB to the README.
2026-08-11 trieing to make a 3d model from the shematic and fixing some issues about the esp32 gipos
    [control.kicad_sch, main board.3mf, main board.FCStd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]
2026-08-11 fixing the layout
    [Programing pins.kicad_sch, control.kicad_sch, led_control.kicad_sch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]
2026-08-11 fixing the wireing mistake
    [pcb.kicad_pcb]
2026-08-11 fixing pt.1
    [BOM.csv, BOM.ods, pcb.kicad_pcb]
2026-08-12 Finding parts and folishing the pcb
    [BOM.ods, pcb.kicad_pcb, pcb.kicad_sch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]
2026-08-12 polishing the bom
    [BOM.ods]
2026-08-12 making normal with for the pcb
    [pcb.csv]
2026-08-12 cleaning the previus 3d model files and start designing the carrier for the main board
    [main board carrier.stl, main board.3mf, main board.FCStd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]
2026-08-13 separating the usb-c
    [Programing pins.kicad_sch, Sensor inputs.kicad_sch, control.kicad_sch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]
2026-08-13 Finishing the usb-c module
    [control.kicad_sch, pcb.kicad_pcb, power.kicad_sch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]
2026-08-21 Finishing the carrier board with the new usb-c modul
    [Programing pins.kicad_sch, Sensor inputs.kicad_sch, control.kicad_sch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]
2026-08-21 making a 3D modell for the Water container and a model for the led cooler
    [led board.stl, watercontainer.stl]
2026-08-22 solving merge conflict pt.2
    [BOM.ods, bom plant.ods]
2026-08-22 cleaning the repository
    [BOM.ods]
2026-08-22 making separate pcbs
    [BOM.csv, BOM.ods, Programing pins.kicad_sch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]
2026-08-22 generating the GERBERS
    [air_and_light_sensor-B_Cu.gbr, air_and_light_sensor-B_Mask.gbr, air_and_light_sensor-B_Paste.gbr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]
2026-08-22 fixing some issues
    [Sensor inputs.kicad_sch, light_sensor.kicad_sch, pcb.kicad_pcb]
2026-08-24 fixing bugs in the frimware
    [pcb.kicad_sch, pump_control.kicad_sch]
2026-08-25 fixed the problem with the bom
    [BOM.csv, esp32 Pins.csv, pcb.kicad_pcb]
2026-08-25 adding silkscreen and finishin the main board
    [pcb-B_Cu.gbr, pcb-B_Mask.gbr, pcb-B_Paste.gbr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]
2026-08-26 Add PCB link to README
    Added a link to view the PCB design on KiCanvas.
2026-08-27 adding pulldown resistor to the SensorBoard
    [air_and_light_sensor-B_Cu.gbr, air_and_light_sensor-B_Mask.gbr, air_and_light_sensor-B_Paste.gbr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]
2026-08-27 merging the BOMs
    [BOM.csv, BOM.ods, air_and_light_sensor.csv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]
2026-08-30 Update BOM.csv with new sensor entries
    Removed outdated components and added new sensors with links.
    [BOM.csv]
2026-08-30 Revise BOM sourcing strategy and pricing details
    Updated sourcing strategy in the BOM section for clarity and added details on component sourcing.
